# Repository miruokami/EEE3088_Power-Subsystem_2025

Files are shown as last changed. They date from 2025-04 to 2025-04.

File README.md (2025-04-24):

# EEE3088F 2025 Micro-Mouse Power Subsystem

Welcome to the repository for the **EEE3088F Micro-Mouse Power Subsystem Project**. This project focuses on designing and implementing a compact and efficient power module for a simplified micro-mouse robot. The goal is to meet all electrical and mechanical specifications, stay within a strict budget, and ensure seamless integration with the larger micro-mouse system.

## 👥 Team Members

- Student 1: SDZLIY001
- Student 2: CHGSHA008

## 📁 Repository Structure
```
> Power subsystem folder with 
  ├── gerbers / # Gerber files for PCB production
  ├── bom (PowerSchematic) / # Bill of Materials (.csv)
  ├── pos / # Pick-and-Place (PnP) files
  ├── screenshots / # Screenshots from JLCPCB uploads
  ├── schematics / # Final schematic file
  ├── pcb_layout 
```

## 🧠 Project Overview

This project involves designing the **power module** for the Micro-Mouse. The rest of the system — processor, sensing module, and motherboard — are pre-designed. The role is to design a subsystem that meets the power needs of the full system while adhering to design and budget constraints.

### Key Objectives

- Power 4 bidirectional motors (2x 200mA, 2x 500mA).
- Include battery monitoring with an INA219 over I2C.
- Implement dual-mode battery charging from a 9V input.
- Provide 3.3V (300mA) and 5V (1.5A) regulated outputs.
- Include external load switching (2x 1A High Side).
- Implement a low-power ON/OFF switch (<30µA OFF draw).
- Integrate USB-C (providing 9V out from USB host).
- Fit within 82x60mm PCB dimensions.
- Use correct JST and 2x16 connector footprints.

## 🛠️ Tools & Technologies

- **EDA Software**: EasyEDA / KiCAD / Altium (for PCB design)
- **Simulation**: LTSpice / MATLAB (optional)
- **PCB Manufacturer**: JLCPCB
- **Microcontroller**: STM32L476 (handled on separate processor board)
- **GitHub**: Version control and collaboration

## ✅ Requirements Summary

| Requirement | Description |
|---|---|
| Power Supply | 3V3 @ 300mA, 5V @ 1.5A |
| Charging | Dual-mode: 200mA and ~600mA |
| Battery Monitoring | INA219 on I2C |
| Motors | 2x 200mA, 2x 500mA |
| USB-C | Must provide 9V out |
| External Loads | 2x 1A, High-Side Switching |
| ON/OFF Switch | <30µA draw in OFF state |
| Budget | $35 per student (includes PCB + components) |

### 🛠️ PCB Ordering  
1. Upload `gerbers/*.zip` to JLCPCB.  
2. Use the provided `bom.csv` and `pos.csv` for assembly.  
3. Ensure components are in stock (check JLCPCB's inventory).
   
## 🧪 Testing Procedure

Testing will be performed using a standardised jig that validates:
- USB-C power output
- Battery charging behavior
- Regulated outputs (5V, 3.3V)
- Motor driver functionality
- INA219 battery monitoring
- ON/OFF switch behavior

## 🔗 Important Links

- [Veritasium Micro-Mouse Inspiration Video](https://www.youtube.com/watch?v=ZMQbHMgK2rw)
- [Micro Robotics Battery](https://www.robotics.org.za/802540)
- [JST Connector Specs](https://www.robotics.org.za/JST-PH-2P-90)
- [JLCPCB](https://jlcpcb.com

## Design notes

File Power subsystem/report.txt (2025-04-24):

Changed footprint C1 from 'Capacitor_SMD:C_0603_1608Metric' to 'Capacitor_SMD:C_0603_1608Metric': : OK
Changed footprint C2 from 'Capacitor_SMD:C_0603_1608Metric' to 'Capacitor_SMD:C_0603_1608Metric': : OK
Changed footprint C3 from 'Capacitor_SMD:C_0603_1608Metric' to 'Capacitor_SMD:C_0603_1608Metric': : OK
Changed footprint C4 from 'Capacitor_SMD:C_0603_1608Metric' to 'Capacitor_SMD:C_0603_1608Metric': : OK
Changed footprint C7 from 'Capacitor_SMD:C_0603_1608Metric' to 'Capacitor_SMD:C_0603_1608Metric': : OK
Changed footprint C8 from 'Capacitor_SMD:C_0603_1608Metric' to 'Capacitor_SMD:C_0603_1608Metric': : OK
Changed footprint C9 from 'Capacitor_SMD:C_0603_1608Metric' to 'Capacitor_SMD:C_0603_1608Metric': : OK
Changed footprint C10 from 'Capacitor_SMD:C_0603_1608Metric' to 'Capacitor_SMD:C_0603_1608Metric': : OK
Changed footprint C12 from 'Capacitor_SMD:C_0603_1608Metric' to 'Capacitor_SMD:C_0603_1608Metric': : OK
Changed footprint C13 from 'Capacitor_SMD:C_0603_1608Metric' to 'Capacitor_SMD:C_0603_1608Metric': : OK
Changed footprint C14 from 'Capacitor_SMD:C_0603_1608Metric' to 'Capacitor_SMD:C_0603_1608Metric': : OK

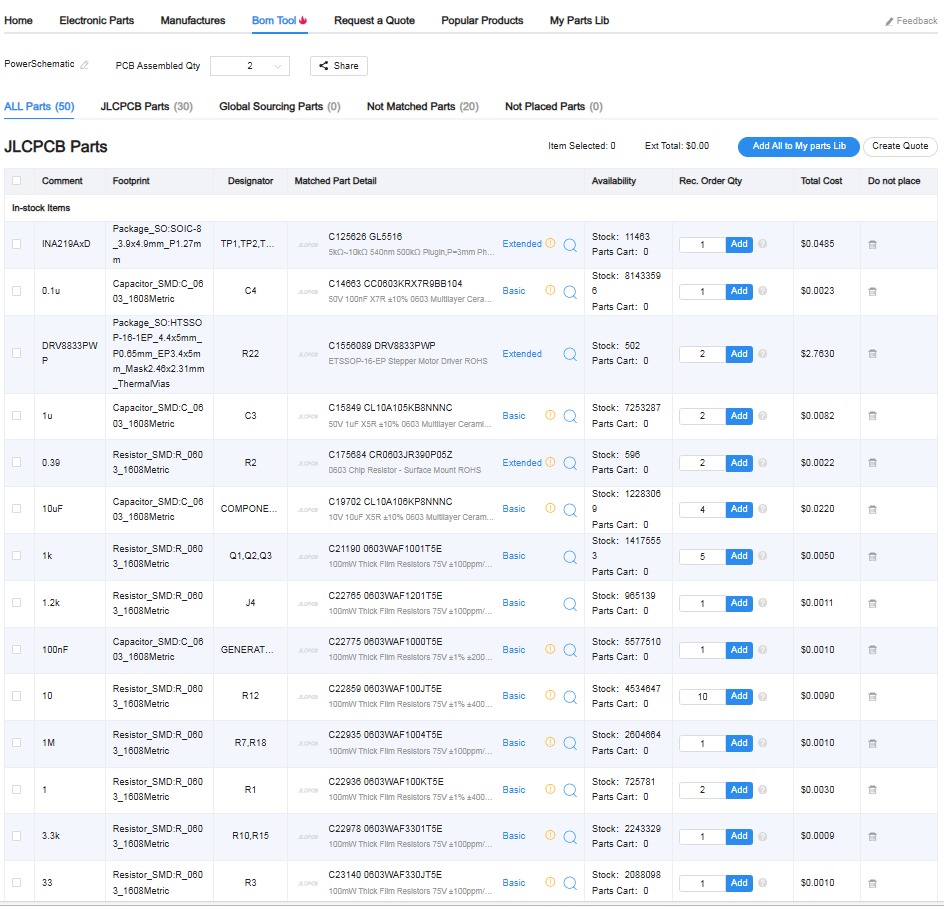
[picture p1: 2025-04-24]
Power subsystem/EEE3088F_Project_JLCPCBBOM_CHGSH008.jpeg

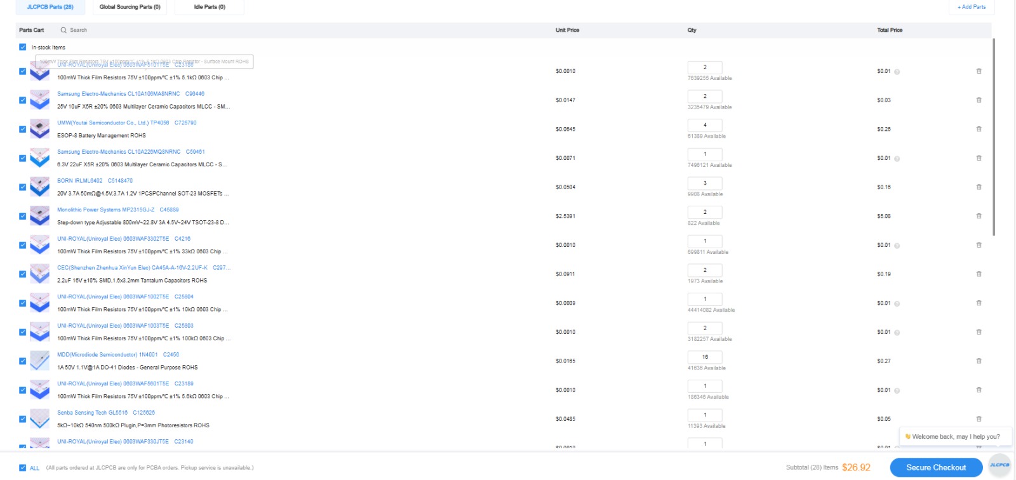
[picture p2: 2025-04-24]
Power subsystem/EEE3088F_Project_JLCPCBBOM_CHGSHA008_CART.jpeg

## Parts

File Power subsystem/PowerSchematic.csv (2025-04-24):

Id | Designator | Footprint | Quantity | Designation | Supplier and ref
1 | TP6,TP2,TP12,TP17,TP1,TP13,TP8,TP3,TP11,TP14,TP5,TP16,TP7,TP9,TP10,TP4 | TestPoint_Pad_1.0x1.0mm | 16 | TestPoint
2 | R22 | R_0603_1608Metric | 1 | 10
3 | U5,U1 | HTSSOP-16-1EP_4.4x5mm_P0.65mm_EP3.4x5mm_Mask2.46x2.31mm_ThermalVias | 2 | DRV8833PWP
4 | R27,R5,R24,R6,R16 | R_0603_1608Metric | 5 | 1k
5 | C13,C4 | C_0603_1608Metric | 2 | 10uF
6 | C9,C10 | C_0603_1608Metric | 2 | 1u
7 | SW1 | Nidec_Copal_SH-7010A | 1 | SW_Push
8 | R9 | R_0603_1608Metric | 1 | 33
9 | R7,R18 | R_0603_1608Metric | 2 | 1
10 | J7,J3 | PinHeader_1x02_P2.54mm_Vertical | 2 | Conn_01x02_Pin
11 | C7,C1 | C_0603_1608Metric | 2 | 10u
12 | R15,R10 | R_0603_1608Metric | 2 | 100k
13 | JP4,JP8,JP3,JP5,JP9,JP7,JP2,JP1,JP6 | SolderJumper-2_P1.3mm_Open_Pad1.0x1.5mm | 9 | SolderJumper_2_Open
14 | R25,R23 | R_0603_1608Metric | 2 | R_LIMIT
15 | R3 | R_0603_1608Metric | 1 | 5.6k
16 | RED1,GREEN1 | LED_0201_0603Metric | 2 | LED
17 | R12 | R_0603_1608Metric | 1 | 1M
18 | U6 | SOIC-8_3.9x4.9mm_P1.27mm | 1 | INA219AxD
19 | C2,C12 | C_0603_1608Metric | 2 | 2.2uF
20 | R19,R8 | R_0603_1608Metric | 2 | 0.39
21 | J5 | PinHeader_1x06_P2.54mm_Horizontal | 1 | B6B-PH-K-S_LF__SN_
22 | C8 | C_0603_1608Metric | 1 | 22u
23 | C14 | C_0603_1608Metric | 1 | 0.1u
24 | C3 | C_0603_1608Metric | 1 | 100nF
25 | R26,R17 | R_0603_1608Metric | 2 | 10K
26 | D9 | D_2114_3652Metric | 1 | D_Schottky
27 | J2 | JST_PH_B2B-PH-K_1x02_P2.00mm_Vertical | 1 | Battery
28 | R20 | R_0603_1608Metric | 1 | 3.3k
29 | R4 | R_0603_1608Metric | 1 | 0.4
30 | R11 | R_0603_1608Metric | 1 | 33k
31 | R2 | R_0603_1608Metric | 1 | 220
32 | J4 | PinHeader_2x16_P2.54mm_Horizontal | 1 | Conn_02x16_Odd_Even
33 | Q1,Q3,Q2 | SOT-23 | 3 | IRLML6402
34 | U3 | SOT-223-3_TabPin2 | 1 | AMS1117
35 | C11,C6 | CP_Elec_4x3 | 2 | 0.01uF
36 | U4 | PinHeader_2x04_P2.54mm_Horizontal | 1 | MP2315GJ
37 | R21 | R_0603_1608Metric | 1 | 10k
38 | C5 | CP_Elec_4x3 | 1 | 10uF
39 | J1 | USB_C_Receptacle_Amphenol_12401610E4-2A | 1 | USB_C_Receptacle
40 | R13,R14 | R_0603_1608Metric | 2 | 5.1k
41 | U2 | SOIC-8-1EP_3.9x4.9mm_P1.27mm_EP2.29x3mm | 1 | TP4056
42 | L1 | L_0201_0603Metric | 1 | 4.7u
43 | R1 | R_0603_1608Metric | 1 | 1.2k

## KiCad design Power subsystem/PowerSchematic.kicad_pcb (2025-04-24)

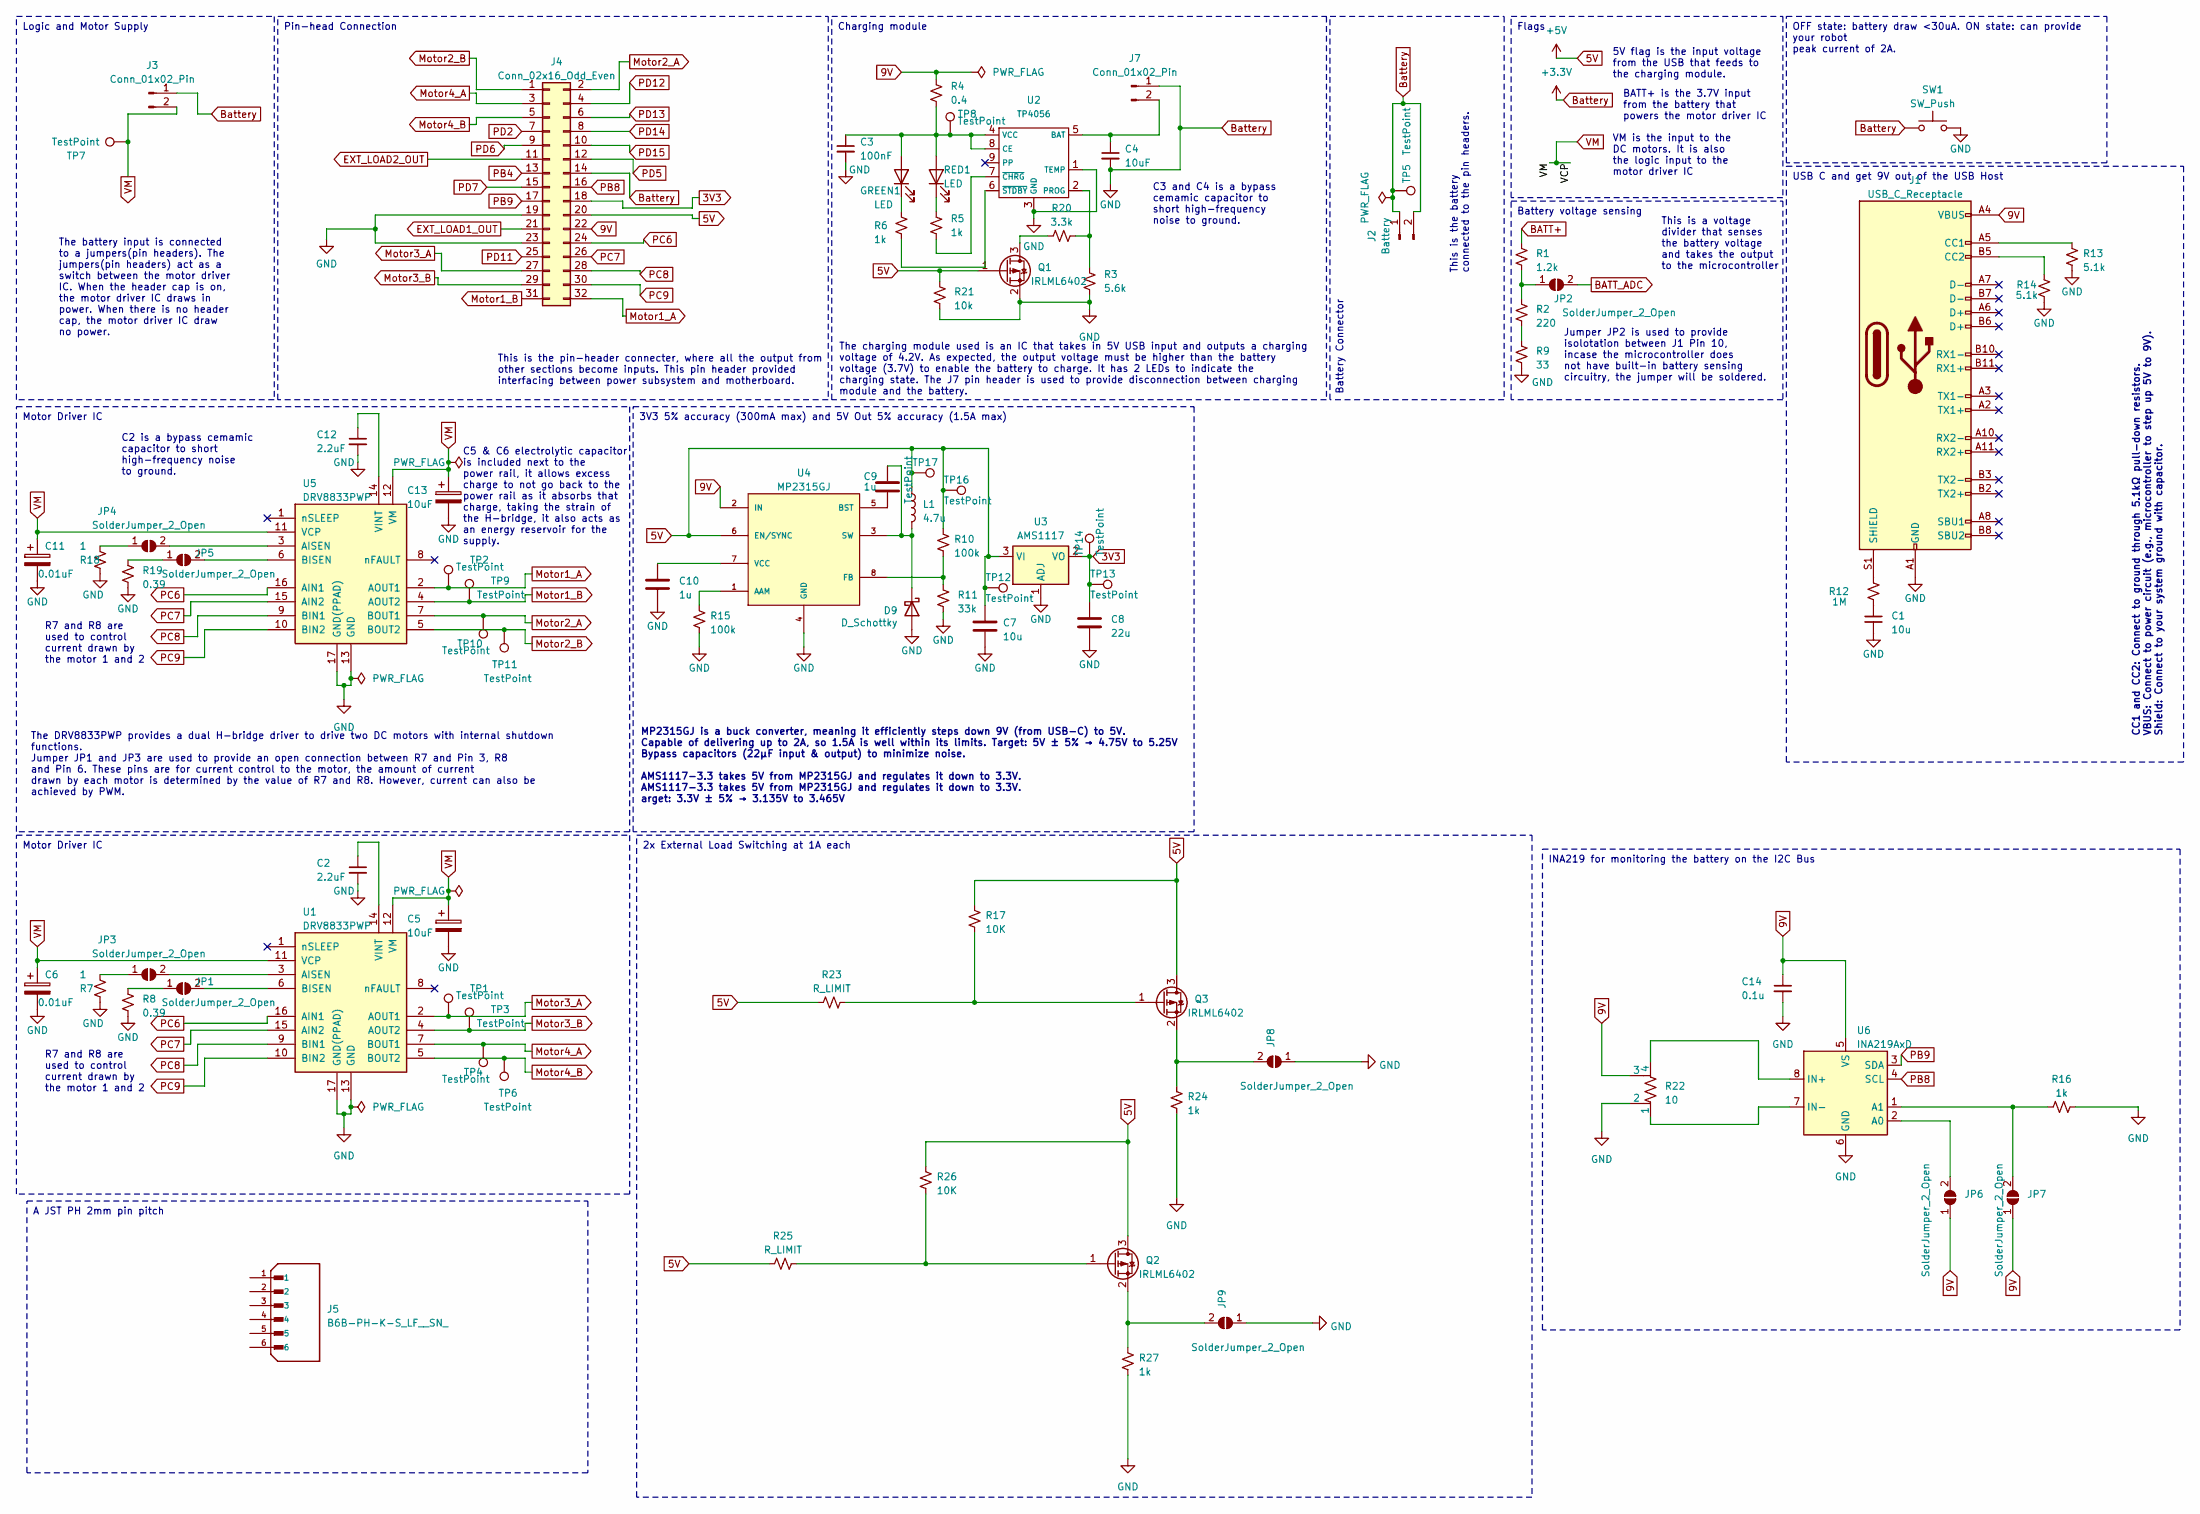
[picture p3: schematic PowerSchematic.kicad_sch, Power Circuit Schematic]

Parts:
C1, C7: 10u; C_0603_1608Metric
C2, C12: 2.2uF; C_0603_1608Metric
C3: 100nF; C_0603_1608Metric
C4, C13: 10uF; C_0603_1608Metric
C5: 10uF; CP_Elec_4x3
C6, C11: 0.01uF; CP_Elec_4x3
C8: 22u; C_0603_1608Metric
C9, C10: 1u; C_0603_1608Metric
C14: 0.1u; C_0603_1608Metric
D9: D_Schottky; D_2114_3652Metric
GREEN1: LED; LED_0201_0603Metric
J1: USB_C_Receptacle; USB_C_Receptacle_Amphenol_12401610E4-2A
J2: Battery; JST_PH_B2B-PH-K_1x02_P2.00mm_Vertical
J3, J7: Conn_01x02_Pin; PinHeader_1x02_P2.54mm_Vertical
J4: Conn_02x16_Odd_Even; PinHeader_2x16_P2.54mm_Horizontal
J5: B6B-PH-K-S_LF__SN_; PinHeader_1x06_P2.54mm_Horizontal; PARTREV N/A
JP1, JP2, JP3, JP4, JP5, JP6, JP7, JP8, JP9: SolderJumper_2_Open; SolderJumper-2_P1.3mm_Open_Pad1.0x1.5mm
L1: 4.7u; L_0201_0603Metric
Q1, Q2, Q3: IRLML6402; SOT-23
R1: 1.2k; R_0603_1608Metric
R2: 220; R_0603_1608Metric
R3: 5.6k; R_0603_1608Metric
R4: 0.4; R_0603_1608Metric
R5, R6, R16, R24, R27: 1k; R_0603_1608Metric
R7, R18: 1; R_0603_1608Metric
R8, R19: 0.39; R_0603_1608Metric
R9: 33; R_0603_1608Metric
R10, R15: 100k; R_0603_1608Metric
R11: 33k; R_0603_1608Metric
R12: 1M; R_0603_1608Metric
R13, R14: 5.1k; R_0603_1608Metric
R17, R26: 10K; R_0603_1608Metric
R20: 3.3k; R_0603_1608Metric
R21: 10k; R_0603_1608Metric
R22: 10; R_0603_1608Metric
R23, R25: R_LIMIT; R_0603_1608Metric
RED1: LED; LED_0201_0603Metric
SW1: SW_Push; Nidec_Copal_SH-7010A
TP1, TP2, TP3, TP4, TP5, TP6, TP7, TP8, TP9, TP10, TP11, TP12, TP13, TP14, TP16, TP17: TestPoint; TestPoint_Pad_1.0x1.0mm
U1, U5: DRV8833PWP; HTSSOP-16-1EP_4.4x5mm_P0.65mm_EP3.4x5mm_Mask2.46x2.31mm_The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
U2: TP4056; SOIC-8-1EP_3.9x4.9mm_P1.27mm_EP2.29x3mm
U3: AMS1117; SOT-223-3_TabPin2
U4: MP2315GJ; PinHeader_2x04_P2.54mm_Horizontal; MPN MP2315
U6: INA219AxD; SOIC-8_3.9x4.9mm_P1.27mm

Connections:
3V3: C8.1, J4.18, TP13.1, TP14.1, U3.2 (VO)
5V: C7.1, L1.1, Q1.1 (G), Q2.3 (D), Q3.3 (D), R10.1, R17.2, R21.1, R23.1, R25.1, R26.2, TP12.1, TP16.1, TP17.1, U3.3 (VI), U4.6 (EN/SYNC)
5V: J4.20
9V: C14.1, J1.A4 (VBUS), J1.A9 (VBUS), J1.B4 (VBUS), J1.B9 (VBUS), J4.22, JP6.1 (A), JP7.1 (A), R4.2, R22.3, U4.2 (IN), U6.5 (VS)
BATT+: R1.1
BATT_ADC: JP2.2 (B)
Battery: C1.2, C2.2, C3.2, C4.2, C5.2, C6.2, C7.2, C8.2, C10.2, C11.2, C12.2, C13.2, C14.2, D9.2 (A), J1.A1 (GND), J1.A12 (GND), J1.B1 (GND), J1.B12 (GND), J2.1, J2.2, J3.1, J4.14, J4.19, J4.23, J7.1, JP8.1 (A), JP9.1 (A), Q1.2 (S), R3.2, R7.2, R8.2, R9.2, R11.2, R13.2, R14.2, R15.2, R16.2, R18.2, R19.2, R21.2, R22.2, R24.1, R27.1, SW1.1, SW1.2, TP5.1, U1.13 (GND), U1.17 (GND(PPAD)), U2.1 (TEMP), U2.3 (GND), U3.1 (ADJ), U4.4 (GND), U5.13 (GND), U5.17 (GND(PPAD)), U6.6 (GND)
EXT_LOAD1_OUT: J4.21
EXT_LOAD2_OUT: J4.11
Motor1_A: J4.32, TP2.1, U5.2 (AOUT1)
Motor1_B: J4.31, TP9.1, U5.4 (AOUT2)
Motor2_A: J4.2, TP10.1, U5.7 (BOUT1)
Motor2_B: J4.1, TP11.1, U5.5 (BOUT2)
Motor3_A: J4.27, TP1.1, U1.2 (AOUT1)
Motor3_B: J4.29, TP3.1, U1.4 (AOUT2)
Motor4_A: J4.3, TP4.1, U1.7 (BOUT1)
Motor4_B: J4.5, TP6.1, U1.5 (BOUT2)
unnamed: C1.1, R12.2
unnamed: C9.1, D9.1 (K), L1.2, U4.3 (SW)
unnamed: C3.1, GREEN1.2 (A), R4.1, RED1.2 (A), TP8.1, U2.4 (VCC), U2.8 (CE)
unnamed: GREEN1.1 (K), R6.2
unnamed: J1.A5 (CC1), R13.1
unnamed: J1.B5 (CC2), R14.1
unnamed: J1.S1 (SHIELD), R12.1
unnamed: C4.1, J7.2, U2.5 (BAT)
unnamed: JP1.1 (A), R8.1
unnamed: JP1.2 (B), U1.6 (BISEN)
unnamed: JP2.1 (A), R1.2, R2.1
unnamed: JP3.1 (A), R7.1
unnamed: JP3.2 (B), U1.3 (AISEN)
unnamed: JP4.1 (A), R18.1
unnamed: JP4.2 (B), U5.3 (AISEN)
unnamed: JP5.1 (A), R19.1
unnamed: JP5.2 (B), U5.6 (BISEN)
unnamed: JP6.2 (B), U6.2 (A0)
unnamed: JP7.2 (B), R16.1, U6.1 (A1)
unnamed: JP8.2 (B), Q3.2 (S), R24.2
unnamed: JP9.2 (B), Q2.2 (S), R27.2
unnamed: Q1.3 (D), R20.1
unnamed: Q2.1 (G), R25.2, R26.1
unnamed: Q3.1 (G), R17.1, R23.2
unnamed: R2.2, R9.1
unnamed: R5.2, RED1.1 (K)
unnamed: C2.1, U1.14 (VINT)
unnamed: R3.1, R20.2, U2.2 (PROG)
unnamed: R5.1, U2.7 (~CHRG)
unnamed: R6.1, U2.6 (~STDBY)
unnamed: R15.1, U4.1 (AAM)
unnamed: C9.2, U4.5 (BST)
unnamed: R10.2, R11.1, U4.8 (FB)
unnamed: C10.1, U4.7 (VCC)
unnamed: C12.1, U5.14 (VINT)
unnamed: R22.4, U6.8 (IN+)
unnamed: R22.1, U6.7 (IN-)
PB4: J4.13
PB8: J4.16, U6.4 (SCL)
PB9: J4.17, U6.3 (SDA)
PC6: J4.24, U1.16 (AIN1), U5.16 (AIN1)
PC7: J4.26, U1.15 (AIN2), U5.15 (AIN2)
PC8: J4.28, U1.9 (BIN1), U5.9 (BIN1)
PC9: J4.30, U1.10 (BIN2), U5.10 (BIN2)
PD2: J4.7
PD5: J4.12
PD6: J4.9
PD7: J4.15
PD11: J4.25
PD12: J4.4
PD13: J4.6
PD14: J4.8
PD15: J4.10
VM: C5.1, C6.1, C11.1, C13.1, J3.2, TP7.1, U1.11 (VCP), U1.12 (VM), U5.11 (VCP), U5.12 (VM)

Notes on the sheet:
Flags
INA219 for monitoring the battery on the I2C Bus
Motor Driver IC
USB C and get 9V out of the USB Host
Battery voltage sensing
3V3 5% accuracy (300mA max) and 5V Out 5% accuracy (1.5A max)
OFF state: battery draw <30uA. ON state: can provide your robot peak current of 2A.
Battery Connector
2x External Load Switching at 1A each
A JST PH 2mm pin pitch
Pin-head Connection
Charging module
Logic and Motor Supply
The charging module used is an IC that takes in 5V USB input and outputs a charging voltage of 4.2V. As expected, the output voltage must be higher than the battery voltage (3.7V) to enable the battery to charge. It has 2 LEDs to indicate the charging state. The J7 pin header is used to provide dis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
This is the pin-header connecter, where all the output from other sections become inputs. This pin header provided interfacing between power subsystem and motherboard.
BATT+ is the 3.7V input from the battery that powers the motor driver IC
C2 is a bypass cemamic capacitor to short high-frequency noise to ground.
R7 and R8 are used to control current drawn by the motor 1 and 2
This is a voltage divider that senses the battery voltage and takes the output to the microcontroller
The battery input is connected to a jumpers(pin headers). The jumpers(pin headers) act as a switch between the motor driver IC. When the header cap is on, the motor driver IC draws in power. When there is no header cap, the motor driver IC draw no power.
C3 and C4 is a bypass cemamic capacitor to short high-frequency noise to ground.
CC1 and CC2: Connect to ground through 5.1kΩ pull-down resistors. VBUS: Connect to power circuit (e.g., microcontroller to step up 5V to 9V). Shield: Connect to your system ground with capacitor.
The DRV8833PWP provides a dual H-bridge driver to drive two DC motors with internal shutdown functions. Jumper JP1 and JP3 are used to provide an open connection between R7 and Pin 3, R8 and Pin 6. These pins are for current control to the motor, the amount of current drawn by each motor is determi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
C5 & C6 electrolytic capacitor is included next to the power rail, it allows excess charge to not go back to the power rail as it absorbs that charge, taking the strain of the H-bridge, it also acts as an energy reservoir for the supply.
This is the battery connected to the pin headers.
MP2315GJ is a buck converter, meaning it efficiently steps down 9V (from USB-C) to 5V. Capable of delivering up to 2A, so 1.5A is well within its limits. Target: 5V ± 5% → 4.75V to 5.25V Bypass capacitors (22µF input & output) to minimize noise. AMS1117-3.3 takes 5V from MP2315GJ and regulates it d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
Jumper JP2 is used to provide isolotation between J1 Pin 10, incase the microcontroller does not have built-in battery sensing circuitry, the jumper will be soldered.
5V flag is the input voltage from the USB that feeds to the charging module.
VM is the input to the DC motors. It is also the logic input to the motor driver IC

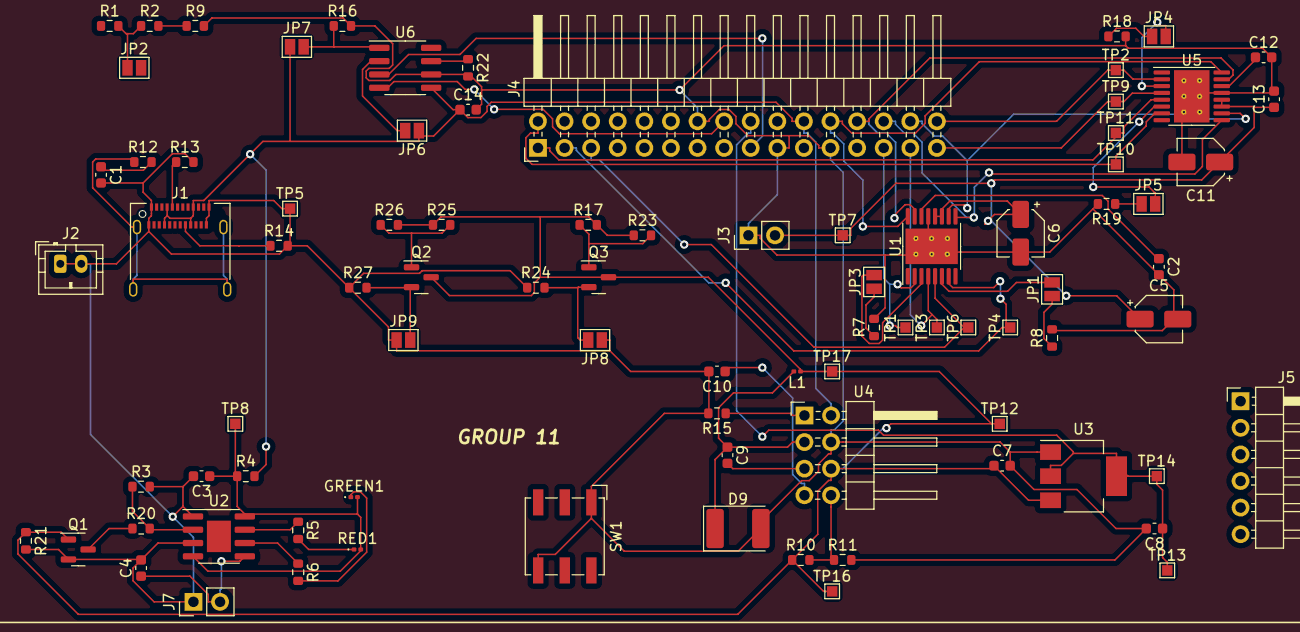
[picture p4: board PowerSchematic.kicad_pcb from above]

Board: 2 copper layers, 86 parts (0 on the bottom side), 55 nets.
